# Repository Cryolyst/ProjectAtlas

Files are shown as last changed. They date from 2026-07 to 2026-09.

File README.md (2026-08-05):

# Project Atlas: Self-Balancing Inverted-Pendulum Robot

## Overview
Project Atlas is a custom-designed, two-wheeled self-balancing robot. This project serves as a comprehensive exploration of embedded systems design, combining a custom 4-layer PCB, real-time control loops, and 3D-printed mechanical enclosures. The system leverages an ESP32 microcontroller to process IMU data and dynamically drive NEMA 17 stepper motors to maintain an upright position.

## System Architecture

### Hardware & Electronics
*   **Microcontroller:** ESP32 (running FreeRTOS for task scheduling)
*   **Sensor:** BNO085 IMU (I2C communication)
*   **Actuation:** 2x NEMA 17 Stepper Motors driven by TMC2209 stepper drivers
*   **Display:** 16x16 Matrix Display for real-time status and diagnostics
*   **Power:** 3S (11.1V) LiPo Battery with LM2596 step-down conversion for logic level
*   **PCB:** Custom 4-layer board (designed in KiCad) featuring isolated ground planes and optimized power delivery for the motor drivers.

### Mechanical Design
*   Custom chassis and component enclosures modeled in Autodesk Fusion 360.
*   Designed with tight tolerances for a low center of gravity to optimize the PID control loop response.

## Repository Structure
*   `/Firmware` - ESP32 C/C++ source code, FreeRTOS tasks, and PID control logic.
*   `/Hardware` - KiCad project files, schematics (PDF), and Gerber files for the 4-layer PCB.
*   `/Hardware/3D Prints` - STL files and Fusion 360 step files for the chassis.

## Current Status
*   **Phase 1:** Breadboard prototyping and base firmware structure - *Complete*
*   **Phase 2:** Custom 4-layer PCB design and manufacturing - *In Progress (Awaiting Delivery)*
*   **Phase 3:** Mechanical 3D printing and physical assembly - *In Progress (Awaiting Delivery)*
*   **Phase 4:** PID tuning and control loop optimization - *Pending*

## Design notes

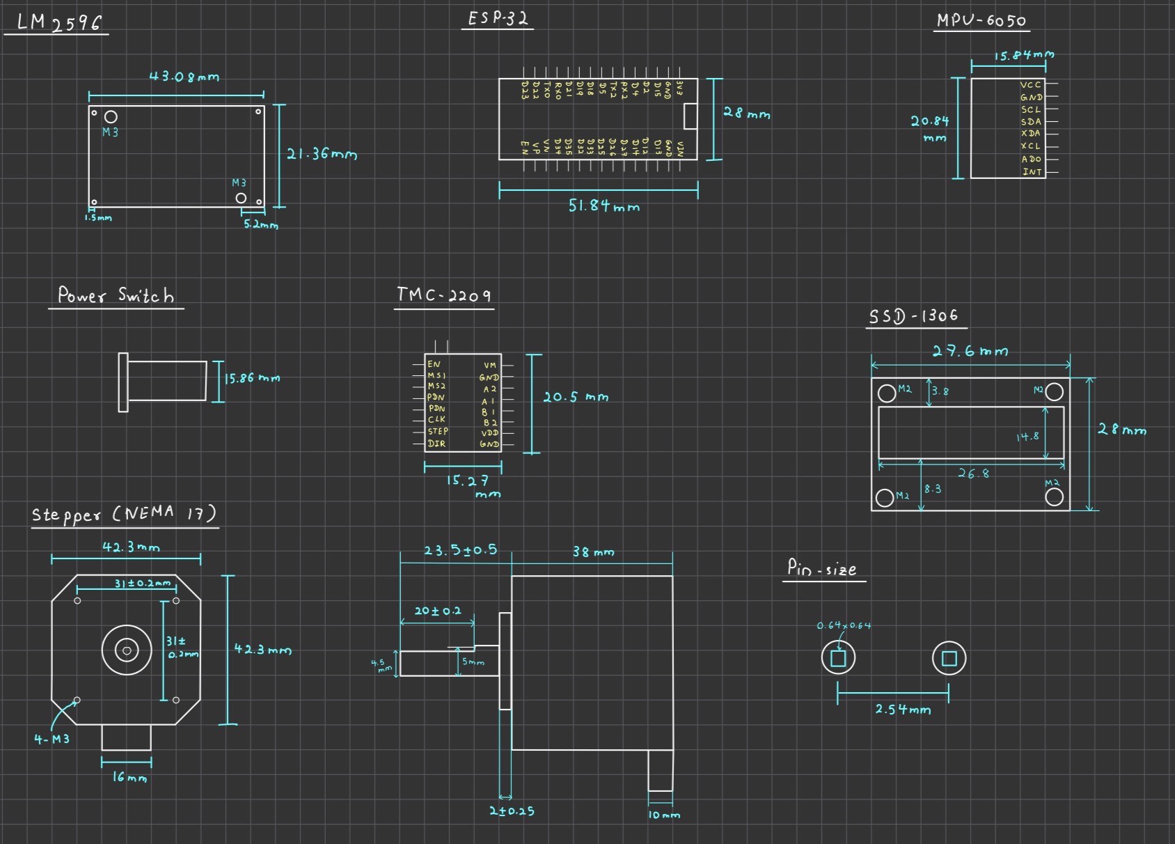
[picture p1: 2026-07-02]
Hardware/Sizing_Schematics.jpg

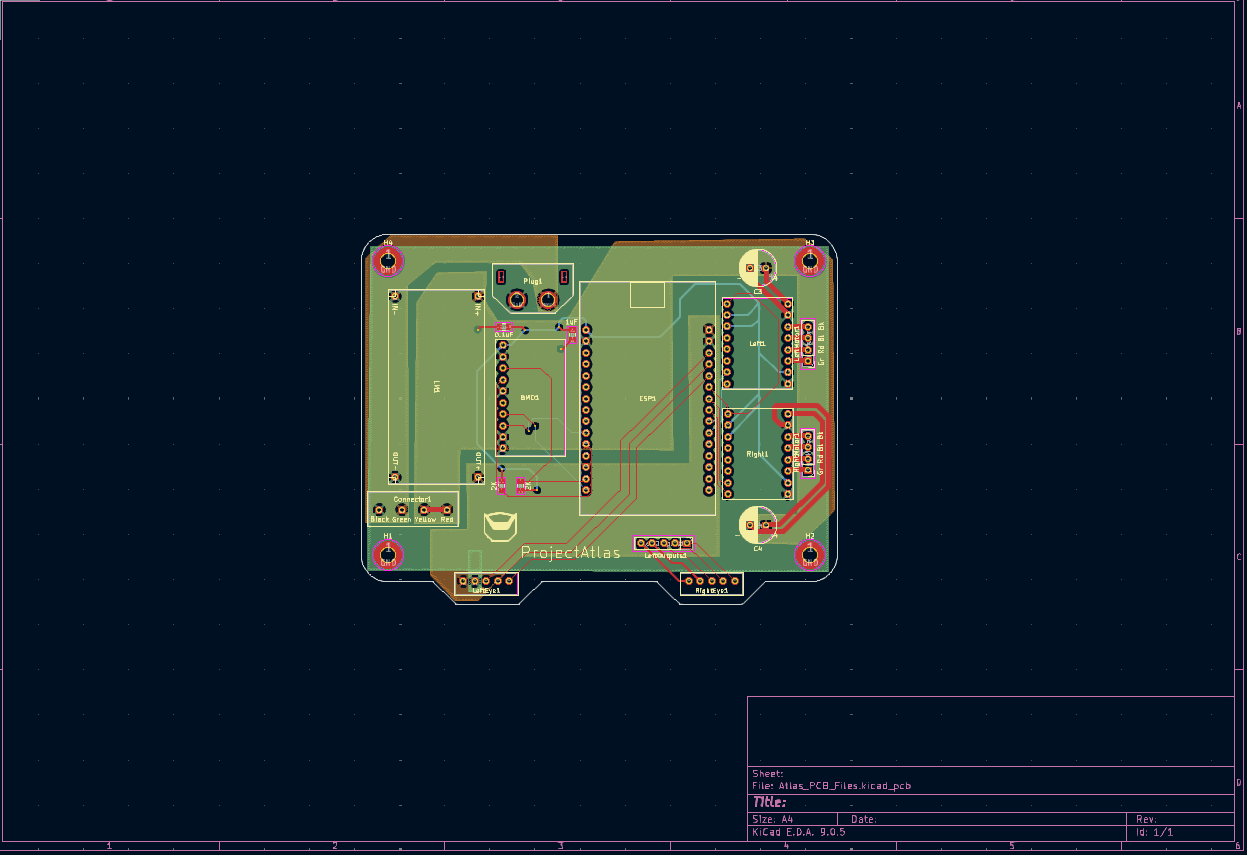
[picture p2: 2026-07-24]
Hardware/AtlasPCBLayout.png

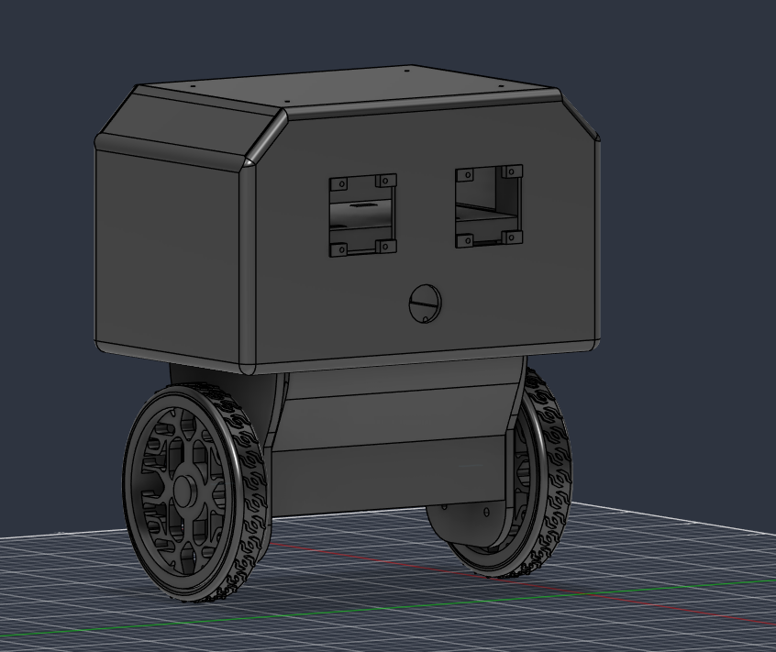
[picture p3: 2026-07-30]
Hardware/Robot3DPrint.png

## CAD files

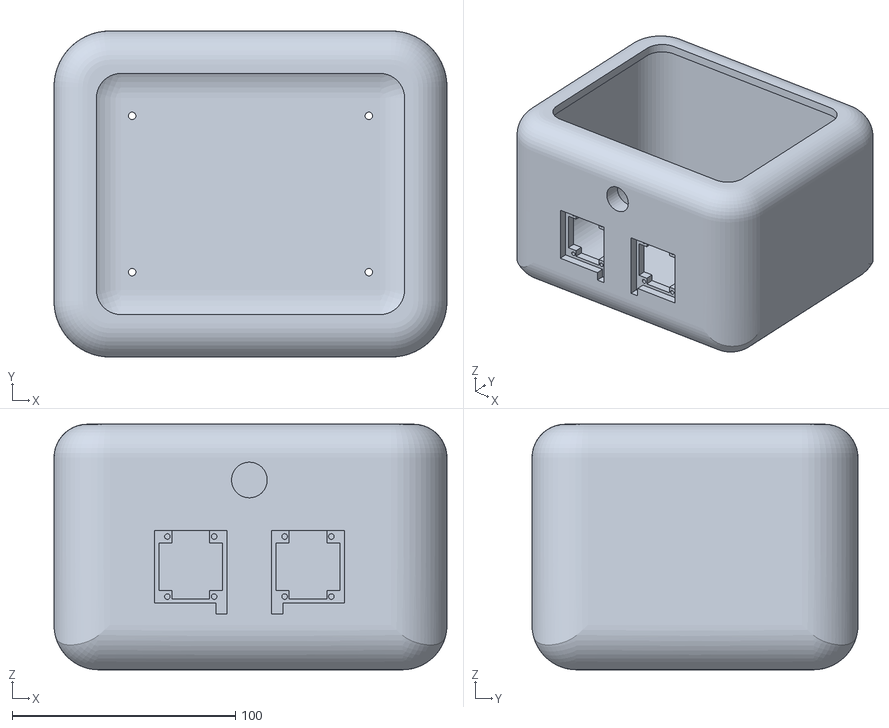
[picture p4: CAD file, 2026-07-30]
Hardware/3D Prints/HeadMaybe.stl
176.0 x 146.0 x 110.0

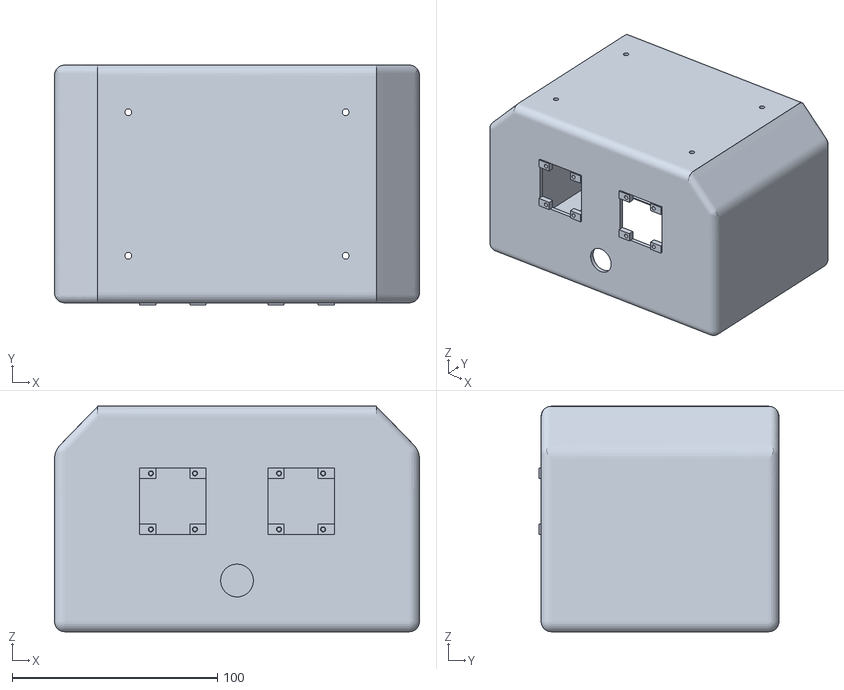
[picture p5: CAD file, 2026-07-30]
Hardware/3D Prints/Head.stl
178.0 x 117.0 x 110.0

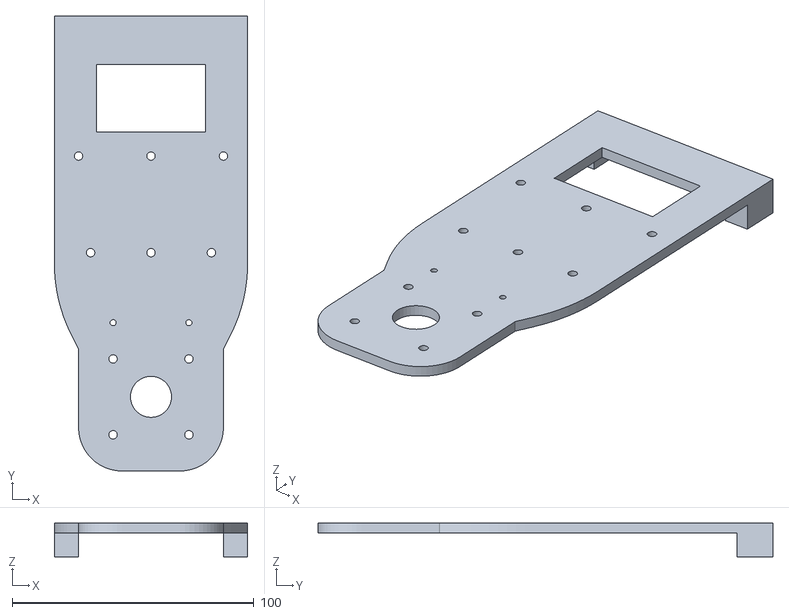
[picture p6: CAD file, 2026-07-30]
Hardware/3D Prints/SidePanels.stl
80.0 x 188.4 x 14.0

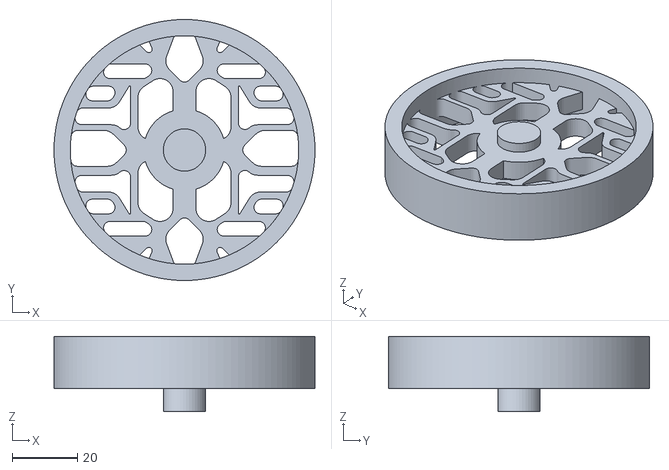
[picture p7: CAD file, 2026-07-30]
Hardware/3D Prints/WheelRimV2.stl
80.0 x 80.0 x 23.0

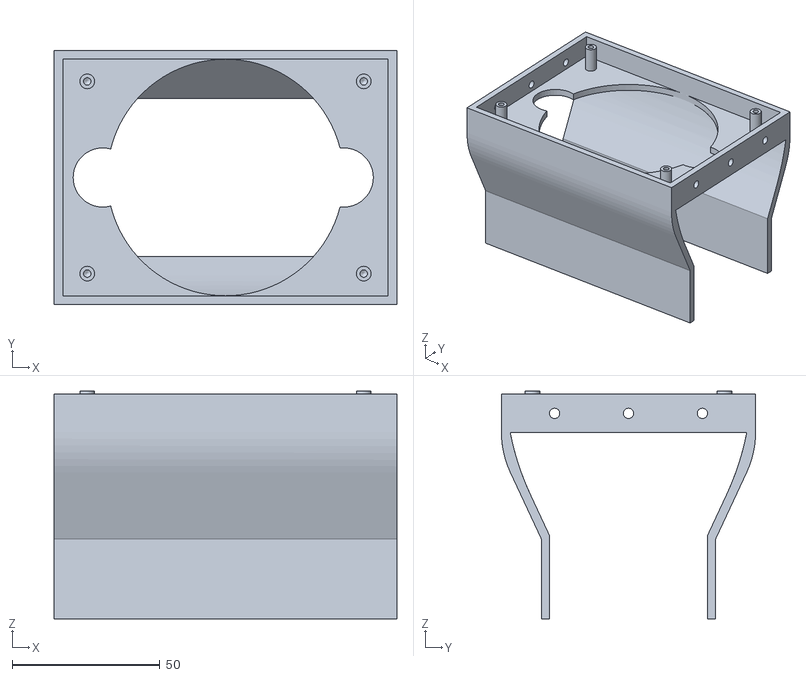
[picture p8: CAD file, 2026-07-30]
Hardware/3D Prints/PCB holder.stl
116.0 x 86.0 x 77.0

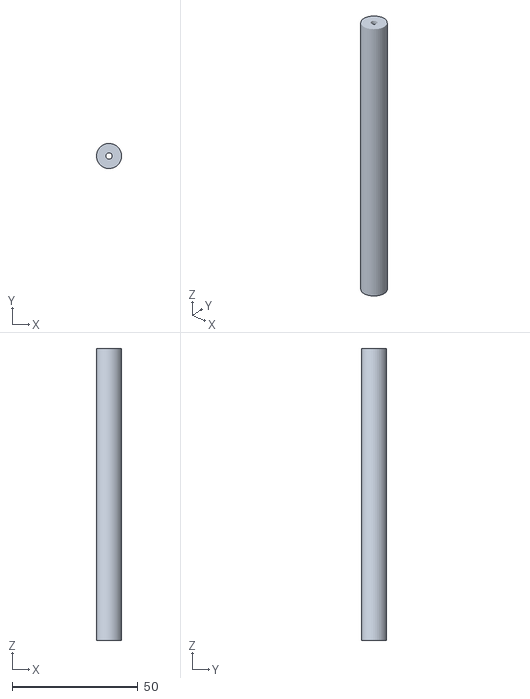
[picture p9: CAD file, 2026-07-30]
Hardware/3D Prints/SupportBeams.stl
9.98 x 9.99 x 116.0

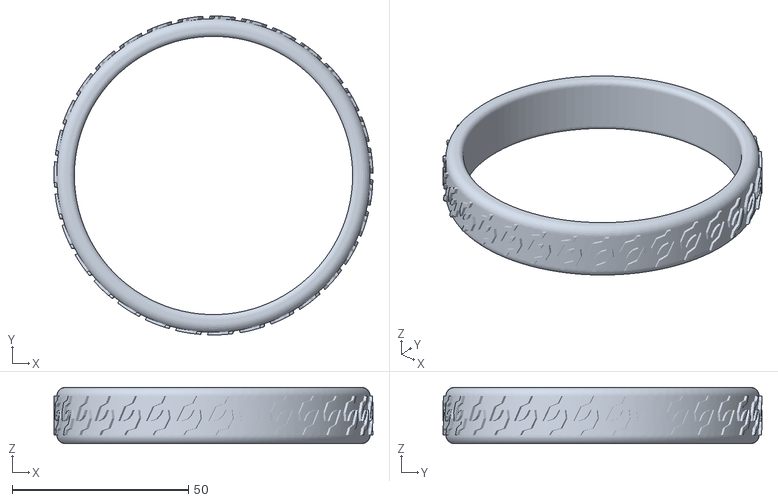
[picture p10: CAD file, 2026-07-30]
Hardware/3D Prints/WheelTireV2.stl
90.6 x 90.6 x 16.0

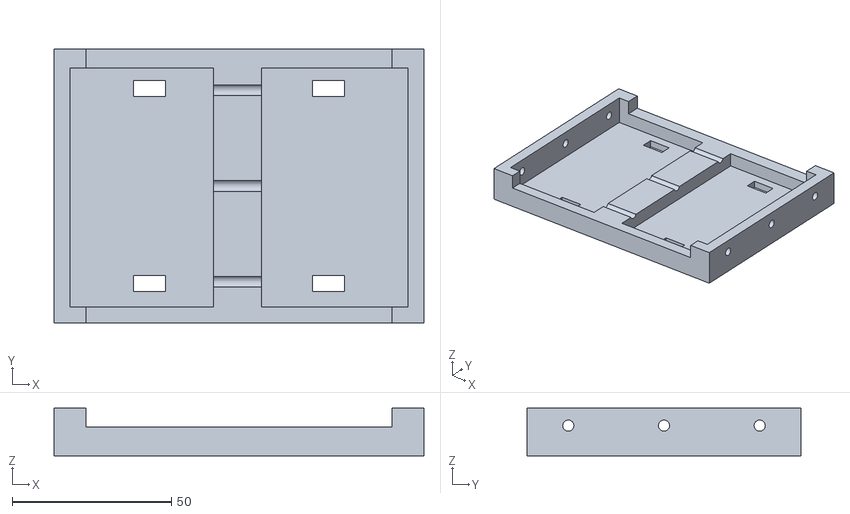
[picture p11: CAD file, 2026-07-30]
Hardware/3D Prints/BatteryHolder.stl
116.0 x 86.0 x 15.0

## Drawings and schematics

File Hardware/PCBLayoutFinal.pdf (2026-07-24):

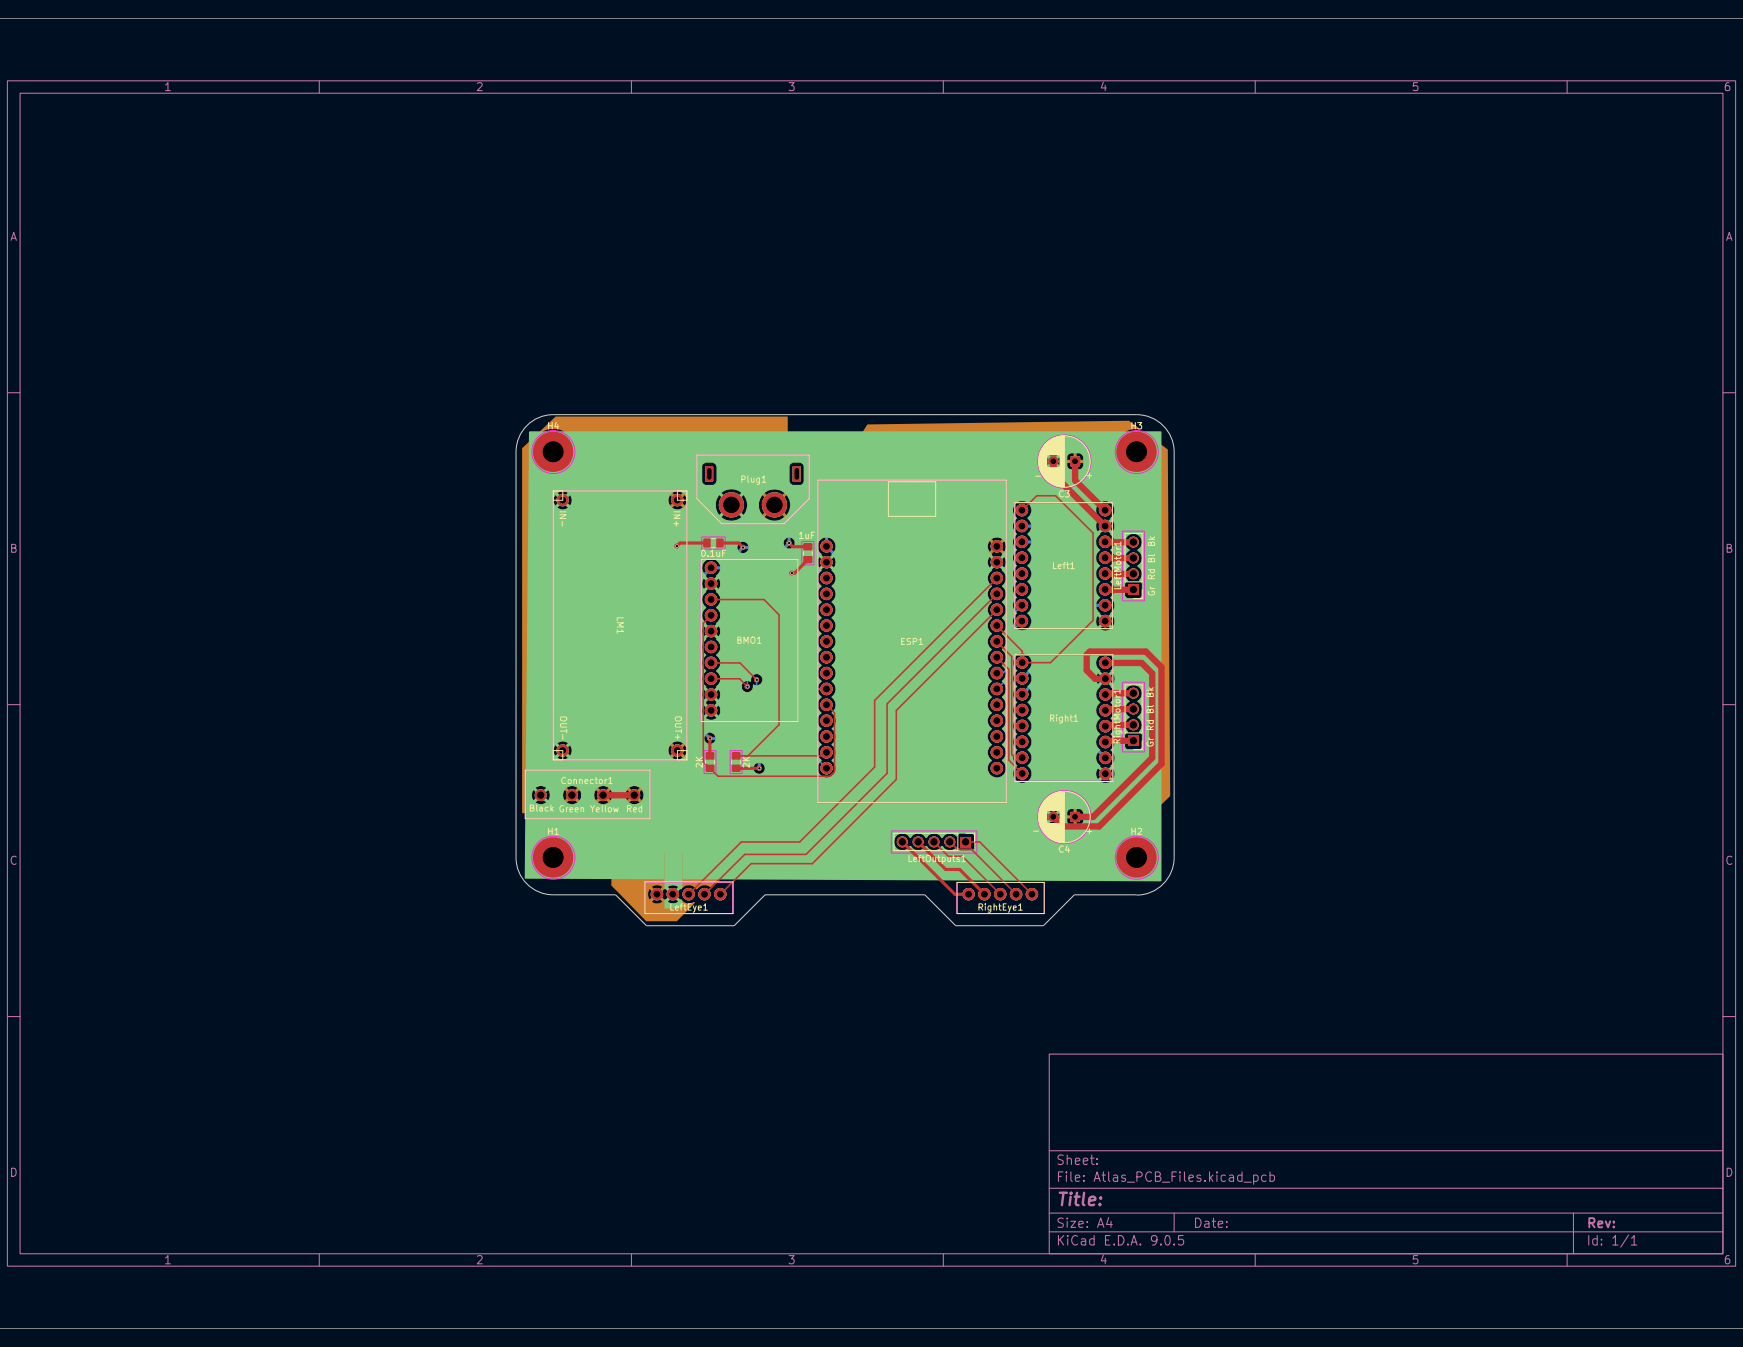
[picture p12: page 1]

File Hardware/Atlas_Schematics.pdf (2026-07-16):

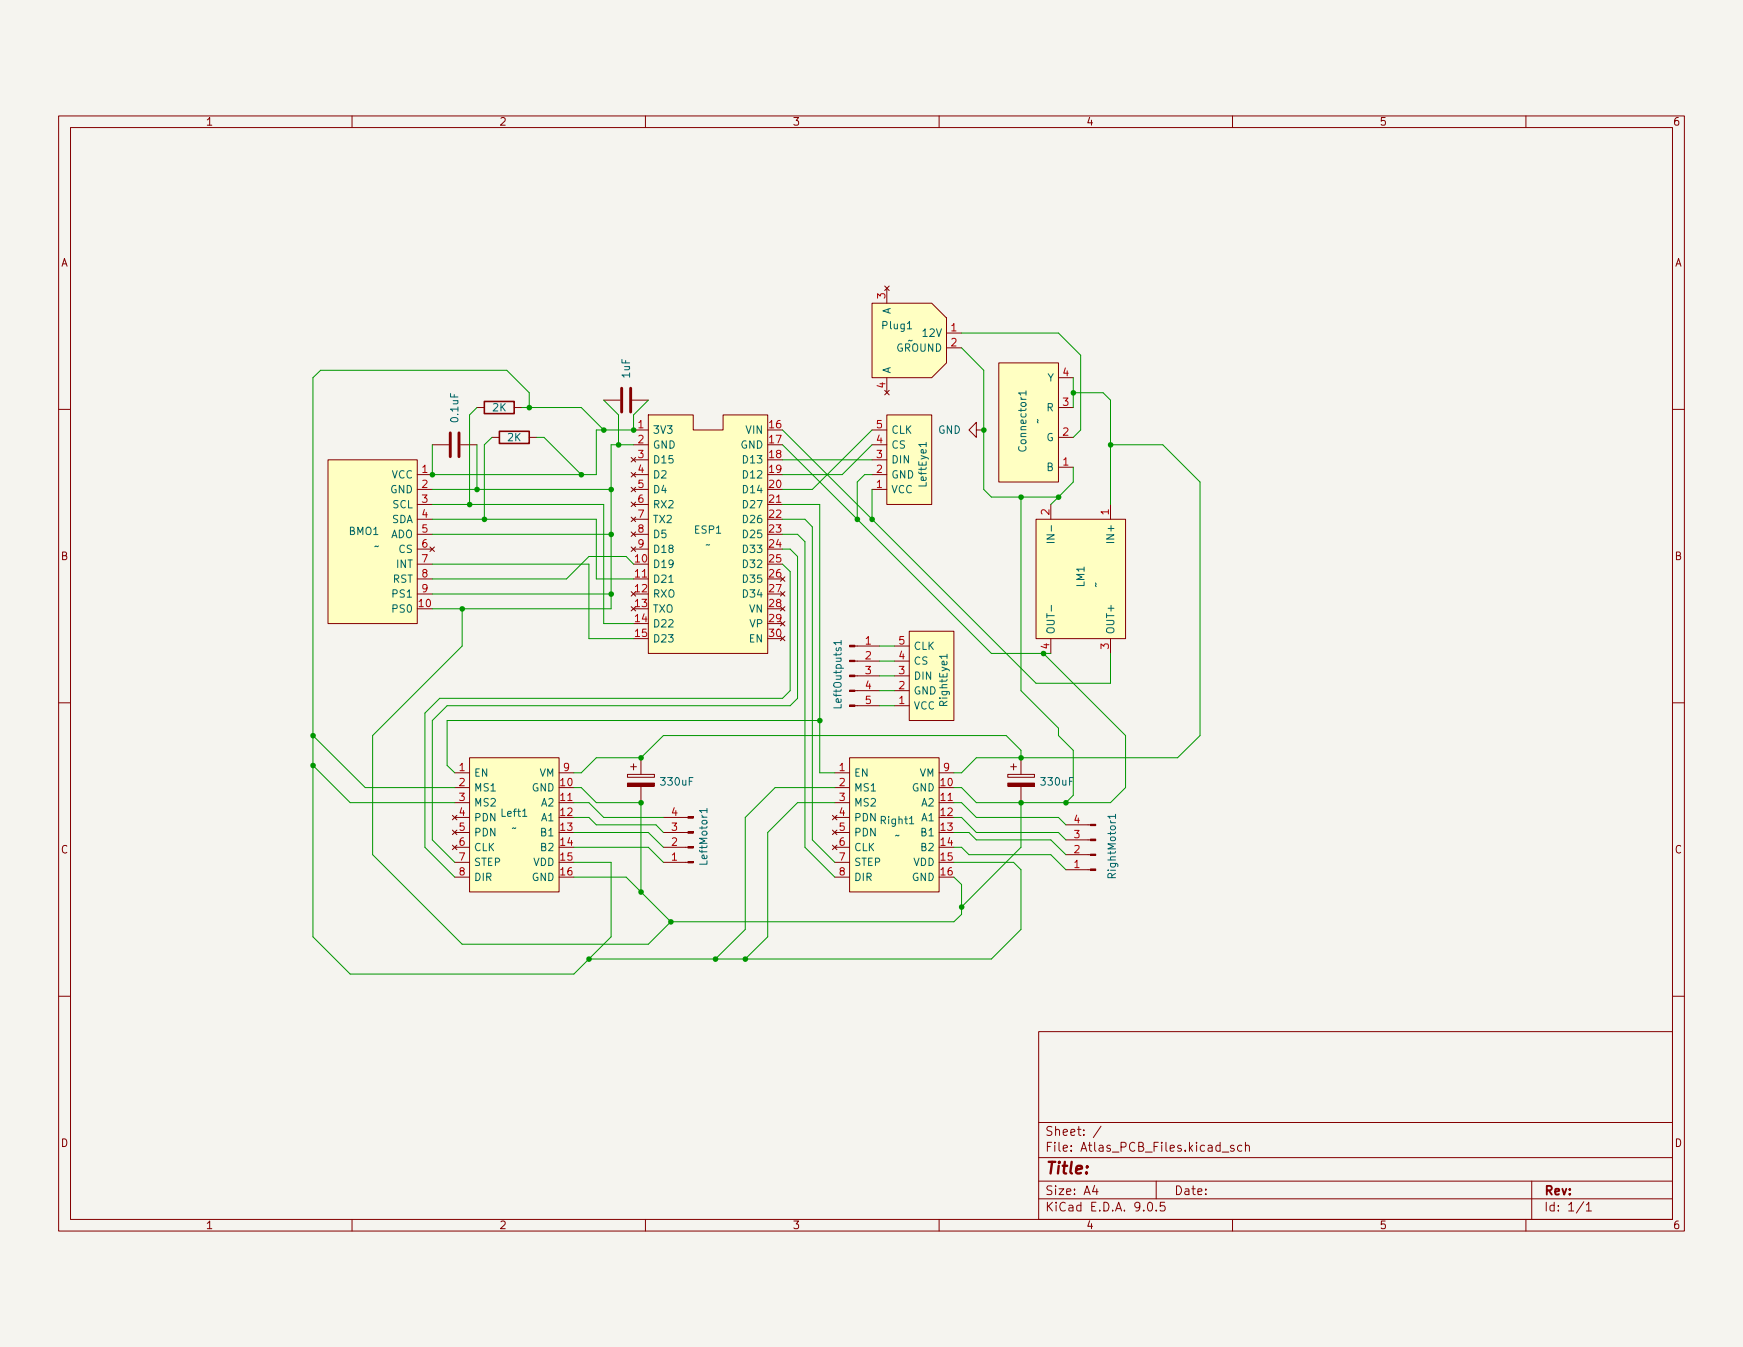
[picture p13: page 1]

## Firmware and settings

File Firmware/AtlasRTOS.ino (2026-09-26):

#include <AccelStepper.h>
#include <Wire.h>
#include "SparkFun_BNO080_Arduino_Library.h"
#include <Arduino.h>
#include <SPI.h>
#include <MD_MAX72xx.h>
#include <esp_task_wdt.h>
#include <BLEDevice.h>
#include <BLEServer.h>
#include <BLEUtils.h>
#include <BLE2902.h>

// PID Values that worked : P800 I20 D350

#define SERVICE_UUID           "6E400001-B5A3-F393-E0A9-E50E24DCCA9E" 
#define CHARACTERISTIC_UUID_RX "6E400002-B5A3-F393-E0A9-E50E24DCCA9E"
#define CHARACTERISTIC_UUID_TX "6E400003-B5A3-F393-E0A9-E50E24DCCA9E"

//--- UI Related Pins and Variables Beginning ---
#define HARDWARE_TYPE MD_MAX72XX::FC16_HW
#define MAX_DEVICES 2

// HSPI Pins
#define HSPI_MOSI 13 // DIN
#define HSPI_MISO 15
#define HSPI_SCLK 14 // CLK
#define HSPI_CS   12 // CS

MD_MAX72XX mx = MD_MAX72XX(HARDWARE_TYPE, HSPI_MOSI, HSPI_SCLK, HSPI_CS, MAX_DEVICES);

// All the eye shapes
const byte openEye[8] = {
  0b00000000,
  0b00111100,
  0b01111110,
  0b11111111,
  0b11111111,
  0b01111110,
  0b00111100,
  0b00000000
};

const byte leftEye[8] = {
  0b00000000,
  0b00000000,
  0b10000001,
  0b11000011,
  0b01100110,
  0b00111100,
  0b00011000,
  0b00000000
};

const byte rightEye[8] = {
  0b00000000,
  0b00011000,
  0b00111100,
  0b01100110,
  0b11000011,
  0b10000001,
  0b00000000,
  0b00000000
};

// --- UI Related Pins and Variables End ---

// Volatile type is used so that this can be changed by one core and read by another
volatile float currentPitch = 0.0;

// P.I.D values
volatile float kP = 100.0;
volatile float kI = 0.0;
volatile float kD = 0.0;

float targetPitch = 0.0; // PLEASE CHANGE WHEN THE PCB ARRIVES
float errorSum = 0.0;
float lastError = 0.0;

// IMU setup
BNO080 IMU;
#define BNO_INT 23
#define BNO_RST 19

// Motor Pins
const int left_stepPin = 33;
const int left_dirPin = 32;
const int right_stepPin = 26;
const int right_dirPin = 25;

// Master Enable Pin for both TMC2209s
const int enablePin = 27;

/* Motors will be running in 1/16 microstepping for smoothness
  MS1 and MS2 on the TMC2209 will be powered by ESP32 3V3
  Also remember that the coils on the NEMA 17 motors are NOT next to each other
  Why is it designed that way), the coils are one pin apart.
*/

// Motor Initialization
AccelStepper leftMotor(1, left_stepPin, left_dirPin);
AccelStepper rightMotor(1, right_stepPin, right_dirPin);

// Two different Tasks for FreeRTOS
TaskHandle_t CoreTaskHandle;
TaskHandle_t UITaskHandle;

// Third one for Bluetooth
TaskHandle_t BLETaskHandle;

class myCallBacks : public BLECharacteristicCallbacks {
  void onWrite(BLECharacteristic *pCharacteristic) {
    String rxValue = pCharacteristic -> getValue().c_str();

    if (rxValue.length() > 0) {
      char command = rxValue[0];
      float value = rxValue.substring(1).toFloat();

      if (command == 'P' || command == 'p') kP = value;
      else if (command == 'I' || command == 'i') kI = value;
      else if (command == 'D' || command == 'd') kD = value;

      Serial.print("Updated -> P: "); Serial.print(kP);
      Serial.print(" I: "); Serial.print(kI);
      Serial.print(" D: "); Serial.print(kD);
    }
  }
};

void BLETask(void *pvParameters) {
  BLEDevice::init("Project Atlas");
  BLEServer *pServer = BLEDevice::createServer();
  BLEService *pService = pServer->createService(SERVICE_UUID);

  // RX Characteristic (Phone -> ESP32)
  BLECharacteristic *pRxCharacteristic = pService->createCharacteristic(
                       CHARACTERISTIC_UUID_RX,
                       BLECharacteristic::PROPERTY_WRITE
                     );
  pRxCharacteristic->setCallbacks(new myCallBacks());

  // TX Characteristic (ESP32 -> Phone)
  BLECharacteristic *pTxCharacteristic = pService->createCharacteristic(
                       CHARACTERISTIC_UUID_TX,
                       BLECharacteristic::PROPERTY_NOTIFY
                     );
  pTxCharacteristic->addDescriptor(new BLE2902());

  pService->start();
  pServer->getAdvertising()->start();
  Serial.println("BLE Ready. Connect via iPhone.");

  for (;;) {
    vTaskDelay(1000 / portTICK_PERIOD_MS);
  }
}

void drawEyes(int deviceIndex, const byte sprite[]) {
  for (int row = 0; row < 8; row++) {
    mx.setRow(deviceIndex, row, sprite[row]); 
  }
}

void CoreTask(void *pvParameters) {

  // Enable TMC2209s
  pinMode(enablePin, OUTPUT);
  digitalWrite(enablePin, LOW);

  // BNO085 Reset Sequence
  pinMode(BNO_RST, OUTPUT);
  digitalWrite(BNO_RST, LOW);
  vTaskDelay(10 / portTICK_PERIOD_MS); // FreeRTOS friendly delay
  digitalWrite(BNO_RST, HIGH);
  vTaskDelay(50 / portTICK_PERIOD_MS);

  // I2C Setup
  Wire.begin();
  Wire.setClock(100000);
  Serial.println("Initializing BNO085...");

  // 0x4A is the address because the IMU's ADO and GND are tied and its decimal is 74
  if (!IMU.begin(74, Wire, BNO_INT)) {
    Serial.println("BNO085 not detected. Check wiring.");
    while(1) { vTaskDelay(10); }  // Stops when the sensor fails
  }
  Serial.println("BNO085 initialized successfully!");

  // We are going to be using the Game Rotation Vector as using the magnetometer would mess up the
  // calculations as the inductance from the motors would interfere with the IMU
  // 5ms = 200Hz
  IMU.enableGameRotationVector(5);

  leftMotor.setMaxSpeed(20000);
  rightMotor.setMaxSpeed(20000);

  // Timing variables for the PID calculation
  unsigned long lastPIDTime = micros();
  const unsigned long PIDInterval = 5000; // 5000 us = 5ms = 200Hz

  esp_task_wdt_add(NULL);

  // Task L O O P Phase
  for (;;) {
    leftMotor.runSpeed();
    rightMotor.runSpeed();

    // Watchdog timer
    esp_task_wdt_reset();

    if (digitalRead(BNO_INT) == LOW) {
      if (IMU.dataAvailable() == true) {
        float pitchRad = IMU.getPitch();
        currentPitch = pitchRad * (180.0 / PI);
      }
    }

    // Check to see if 5ms has passed on the PID loop
    if (micros() - lastPIDTime >= PIDInterval) {
      lastPIDTime = micros();

        // --------- PID ---------
        float error = targetPitch - currentPitch;

        // Integral Calculation
        errorSum += error;
        errorSum = constrain(errorSum, -2000, 2000);

        // Derivative Calculation
        float dError = error - lastError;
        lastError = error;

        // PID equation
        float PID = (kP * error) + (kI * errorSum) + (kD * dError); 

        leftMotor.setSpeed(PID);
        rightMotor.setSpeed(-PID);
    }
  }
}

void UITask(void *pvParameters) {

  mx.begin();
  mx.control(MD_MAX72XX::INTENSITY, 5);
  mx.clear();

  for (;;) {
    float localPitch = currentPitch;

    if (abs(localPitch) > 15.0) {
      drawEyes(1, leftEye);
      drawEyes(0, rightEye);
    } else {
      drawEyes(1, openEye);
      drawEyes(0, openEye);
    }

    // Serial for Testing
    Serial.print("Pitch: ");
    Serial.println(localPitch);
    vTaskDelay(50 / portTICK_PERIOD_MS);
  }
}

void setup() {
  Serial.begin(115200);
  // Core 1 Balancing Task (Priority 1 - High)
  xTaskCreatePinnedToCore(
    CoreTask, "CoreTask", 10000, NULL, 1, &CoreTaskHandle, 1
  );

  // Core 0 UI Task (Priority 0 - Low)
  xTaskCreatePinnedToCore(
    UITask, "UITask", 10000, NULL, 0, &UITaskHandle, 0
  );

  xTaskCreatePinnedToCore(
    BLETask, "BLETask", 10000, NULL, 0, &BLETaskHandle, 0
  );
}

void loop() {
  vTaskDelete(NULL);
}

// Note to self, motors A+ -> A2, A- -> A1, B+ -> B2, B- -> B1
// Motor Wires, Black (A+), Green (B+), Blue(A-), Red(B-)

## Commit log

2026-07-07 Update README.md
    Burned the GY531 and switched it for the upgrade
2026-07-14 Final code without PID Values
